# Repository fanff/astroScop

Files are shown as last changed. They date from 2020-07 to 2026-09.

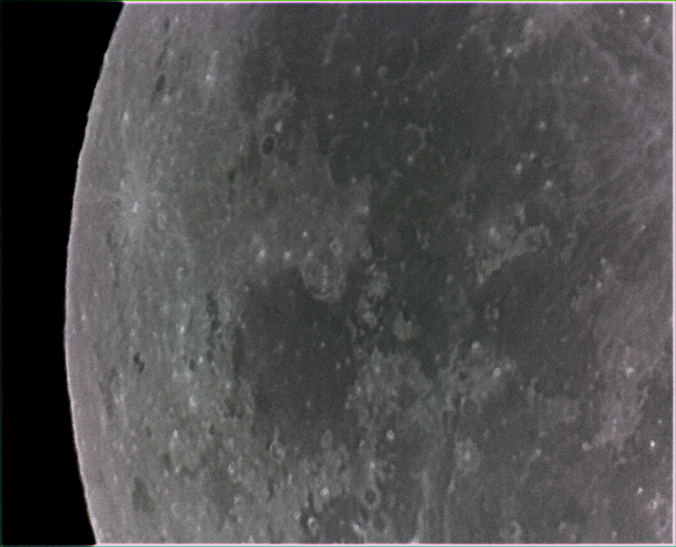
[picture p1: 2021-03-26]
backapp/testimgs/moon2.jpg

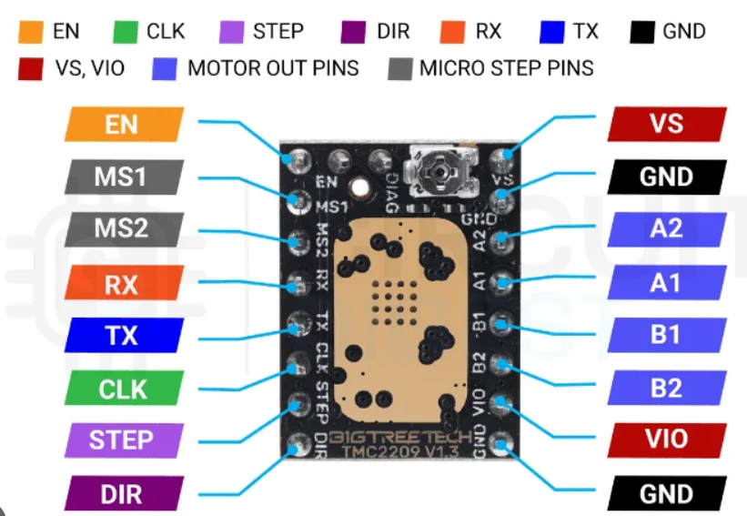
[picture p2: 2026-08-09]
firm/TMC2209.png

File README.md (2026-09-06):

# astroScop

Raspberry Pi HQ camera + dual-axis stepper telescope control, with a Vue UI and optional Bayer post-processing for Siril.

```text
UI (wasp) ──WebSocket──► rootserver :8765
                              │
              ┌───────────────┼───────────────┐
              ▼               ▼               ▼
        cam_picamera2    motorControl     guideControl
        (picamera2)      (USB serial)     (isolate+PI)
              │               │               │
              ▼               ▼               │
           IMX477          Pico 2 W ◄─────────┘
                           (ASC + DEC, mixer)
```

## Layout

| Path | Role |
|---|---|
| [`backapp/`](backapp/) | Pi services: WebSocket hub, HQ camera worker, motor worker |
| [`firm/pico2w/`](firm/pico2w/) | MicroPython firmware for Pico 2 W (ASC/DEC STEP/DIR) |
| [`webapp/wasp/`](webapp/wasp/) | Vue 3 + Vite control UI |
| [`postprocessing/`](postprocessing/) | Bayer `.npy` → CFA FITS for Siril (`astroscop-pp`) |

## Pi services

Installed via [`backapp/deploy/install_on_pi.sh`](backapp/deploy/install_on_pi.sh)
(after syncing code with [`backapp/deploy/deploy.ps1`](backapp/deploy/deploy.ps1) / [`backapp/deploy/deploy.sh`](backapp/deploy/deploy.sh)):

| systemd unit | Process |
|---|---|
| `astroscop-rootserver` | [`backapp/rootserver.py`](backapp/rootserver.py) — WS hub |
| `astroscop-camera` | [`backapp/cam_picamera2.py`](backapp/cam_picamera2.py) — HQ capture + preview |
| `astroscop-motor` | [`backapp/motorControl.py`](backapp/motorControl.py) — rates ↔ Pico |
| `astroscop-guide` | [`backapp/guideControl.py`](backapp/guideControl.py) — isolate + PI; trims to mixer (`GUIDE_ENABLE` still required) |

Camera settings contract (wire format, slow/fast fields): [`backapp/docs/camera-settings-contract.md`](backapp/docs/camera-settings-contract.md).  
Hardware / modes / science notes: [`backapp/docs/pi-hq-camera.md`](backapp/docs/pi-hq-camera.md).

## Firmware (Pico 2 W)

See [`firm/README.md`](firm/README.md) and [`firm/pico2w/README.md`](firm/pico2w/README.md).

```bash
cd firm/pico2w
mpremote connect COM5 cp main.py :main.py
mpremote connect COM5 reset
```

Host client: [`backapp/pico_motor.py`](backapp/pico_motor.py).

## UI (wasp)

```bash
cd webapp/wasp
npm install
npm run serve    # dev
npm run build    # production
```

Pi deploy (compiled static files on **port 80**, hub still `ws://<host>:8765`).
SSH host defaults to `piscope`; set `ASTROSCOP_PI_HOST` for another Pi (e.g. `piscope2`).

```bash
# Windows — backend then UI
$env:ASTROSCOP_PI_HOST = "piscope2"
powershell -File backapp/deploy/deploy.ps1
cd webapp/wasp; npm run deploy:pi

# bash
ASTROSCOP_PI_HOST=piscope2 ./backapp/deploy/deploy.sh
ASTROSCOP_PI_HOST=piscope2 ./webapp/wasp/deploy/deploy.sh
```

See [`webapp/wasp/README.md`](webapp/wasp/README.md).

## Post-processing

Convert science Bayer captures to Siril-friendly FITS:

```bash
cd postprocessing
# see postprocessing/README.md
```

## Evolution (planning)

| Document | Status |
|---|---|
| [`docs/evolution-vision-motor-control-loop.md`](docs/evolution-vision-motor-control-loop.md) | Plan: camera-star PID trims on top of sidereal ASC + DEC (polar alignment is close, not perfect) |

## Dev notes

- [`backapp/`](backapp/) is **uv-managed** (`pyproject.toml` + `uv.lock`). Dev: `cd backapp && uv sync`.
- Pi install does **not** need uv: on a host run [`backapp/deploy/export_pi_requirements.sh`](backapp/deploy/export_pi_requirements.sh), sync `deploy/requirements.generated.txt` to the Pi, then run [`backapp/deploy/install_on_pi.sh`](backapp/deploy/install_on_pi.sh). That script creates a `.venv` with `--system-site-packages`, `pip install`s the export, and keeps **apt** packages for picamera2 / numpy / opencv / PIL.
- Preview helpers live in [`backapp/imgutils.py`](backapp/imgutils.py); Bayer science saves go through [`backapp/cam_storage.py`](backapp/cam_storage.py).

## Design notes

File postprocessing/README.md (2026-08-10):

# Offline Bayer → Siril CFA FITS

Convert astroScop science captures (`frame_*_bayer.npy` + `frame_*_meta.json`) into a numbered series of **undebayered CFA** FITS files that Siril can stack.

This package is for an **x86 processing PC**. It is not deployed on the Pi or telescope.

## Requirements

- Python ≥ 3.12
- [uv](https://github.com/astral-sh/uv) (recommended)

## Install / run

```powershell
cd postprocessing
uv sync --group dev
uv run astroscop-pp convert D:\cko\astropic\sat1 -o D:\cko\astropic\sat1_siril --basename lights
```

Useful flags:

| Flag | Meaning |
|---|---|
| `--limit N` | Convert only the first N frames (smoke test) |
| `--dry-run` | List planned outputs without writing |
| `--overwrite` | Replace existing `.fits` |
| `--no-recursive` | Do not scan one subdirectory level (`bigs/`, etc.) |

## What the converter does

1. Pairs `*_bayer.npy` with `*_meta.json`, sorted by `sequence`
2. Crops stride padding using `raw.configured_size` `[W, H]` (e.g. 2032 → 2028)
3. Maps `SBGGR12` → FITS `BAYERPAT=BGGR` (no demosaic)
4. Writes `lights_00001.fits`, `lights_00002.fits`, … plus `conversion_manifest.json`

## Siril

1. Set the working directory to the output folder.
2. In **Conversion**, add the `.fits` files and use sequence name `lights` (or load the sequence if already named).
3. Keep **Debayer unchecked** through calibration / registration of OSC lights; debayer after preprocessing if you follow a colour workflow.
4. For current HQ captures, Bayer pattern should read as **BGGR**.

## Tests

```powershell
cd postprocessing
uv run pytest
```

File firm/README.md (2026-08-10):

# Telescope firmware (Pico 2 W)

MicroPython firmware for the **Raspberry Pi Pico 2 W**.

Host protocol (USB serial commands for the Raspberry Pi) lives next to the boot script:

→ **[`pico2w/README.md`](pico2w/README.md)**

Pi host for ASC+DEC is `backapp/motorControl.py` + `backapp/pico_motor.py` (systemd: `astroscop-motor`).

## Current status

- **ASC** and **DEC** motors are wired and controlled in **STEP/DIR** standalone mode (no TMC UART config yet).
- Pico emits regular STEP pulses from sparse USB commands (`asc` / `dec` with `dir`, `step_us`).
- Rate setpoints ease over ~100 ms (signed rate); step deadline is not reset on change.
- **CLK** on the TMC is left **open** (internal oscillator). Do not drive it from the Pico.
- TMC PDN UART is still unresolved; probes are kept under `pico2w/tests/`.

Current is set with the TMC **VREF** pot until UART works. Keep common **GND** between Pico, TMC, and 12V PSU (−).

## Hardware

The Pico 2 W will drive **two TMC2209** boards (ASC + DEC).

| Signal | Role (today) |
|---|---|
| **EN** | Enable / disable driver (active-low `ENN`) |
| **STEP** / **DIR** | Motion |
| **CLK** | Leave open on TMC |
| **PDN / UART** | Planned; not used by `main.py` yet |

### Pin map (Pico 2 W ↔ TMC2209)

Physical pin numbers are the board edge connector pins.

**Motor 1 — ASC**

| TMC2209 | Pico 2 W GPIO | Board pin | Color |
|---|---|---|---|
| DIR | GP10 | 14 | Green |
| STEP | GP11 | 15 | White |
| EN | GP12 | 16 | Grey |
| CLK | (open on TMC) | — | — |
| PDN (future UART) | GP16 / GP17 + 1k single-wire | 21 / 22 | Blue / Yellow |

**Motor 2 — DEC**

| TMC2209 | Pico 2 W GPIO | Board pin | Color |
|---|---|---|---|
| DIR | GP18 | 24 | Green |
| STEP | GP19 | 25 | White |
| EN | GP20 | 26 | Grey |
| CLK | (open on TMC) | — | — |
| PDN (future UART) | GP8 / GP9 + 1k single-wire | 11 / 12 | Blue / Yellow |

## First-run setup

### 1. Flash MicroPython

1. Download the official MicroPython UF2 for **Pico 2 W**:
   https://micropython.org/download/RPI_PICO2_W/
2. Hold **BOOTSEL**, plug in USB, release BOOTSEL.
3. Copy the `.uf2` onto the `RPI-RP2` drive.

### 2. Install the upload tool

```bash
uv tool install mpremote
```

## Upload firmware

```bash
cd firm/pico2w
mpremote connect COM5 cp main.py :main.py
mpremote connect COM5 reset
```

On this machine the Pico is usually **COM5** (`2e8a:0005`).

Smoke-test over the USB REPL:

```bash
mpremote connect COM5 repl
```

Then type:

```text
ping
asc dir=1 step_us=2000
dec dir=0 step_us=2000
status
stop
```

### Hardware tests (optional)

```bash
mpremote connect COM5 run tests/test_step_burst.py
mpremote connect COM5 run tests/test_dec_step_burst.py
mpremote connect COM5 run tests/test_tmc_uart_pdn.py
```

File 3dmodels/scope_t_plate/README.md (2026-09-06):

# Scope T-plate

OpenSCAD **T-shaped** mounting plate for a scope on a bar. Same geometry
family as `marks_holder`, with each feature named and switchable.

## Features

Each block is a Customizer group. Booleans under **Features** turn cuts on or
off without changing the T outline.

- **T body** — horizontal crossbar plus vertical stem. `stem_length` is how
  far the stem extends past the bar; `stem_from_center` slides the stem along Y
- **Rails** — two rectangular channels on the underside of the crossbar
  (`rail_length`, `rail_width`, `rail_depth`, `rail_inner_gap`)
- **Crossbar M4 taps** — two Ø3.3 mm tap-drill holes on the bar, spaced by
  `m4_tap_spacing` and centred on the bar midpoint
- **Deck** — thinner filling plate in the open T corner, united with the T
  before corner rounding, with a 10×10 mm grid of Ø2.5 mm M3 tap holes
  (`deck_hole_spacing`, `m3_tap_diameter`)
- **Scope mount** (optional) — two 1/4"-20 clearance holes on the crossbar,
  mirrored about the plate centre along Y; `scope_screw_from_center` is the
  offset of each hole from that centre
- **Pi camera mount** (optional) — M3 through-hole on the stem plus an M3-wide
  arc slot centred on that hole so the camera can pivot; `pi_arc_angle` is the
  total sweep, `m3_clearance_diameter` is the pass-through size

## Mode

Customizer **Mode** → `testing` or `normal`.

Switched sizes (testing → normal): plate height, deck height, and
deck max X. Other dimensions stay shared.

## Usage

Open `scope_t_plate.scad` in [OpenSCAD](https://openscad.org/), adjust
parameters if needed, then **Export → STL**.

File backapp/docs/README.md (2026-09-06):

# astroScop camera docs

Docs for the Raspberry Pi HQ (IMX477) camera path used by agents and operators.

| Document | Purpose |
|---|---|
| **[`camera-settings-contract.md`](camera-settings-contract.md)** | **Start here for rootserver + UI work** — wire format, slow/fast fields, forbidden keys, WS messages |
| [`pi-hq-camera.md`](pi-hq-camera.md) | Hardware, sensor modes, science notes, safe live testing on `piscope` |
| [`hq-camera-capability-report.md`](hq-camera-capability-report.md) | Verified capability suite results (modes, exposure trust, ScalerCrop behaviour) |
| [`cam-settings-bench-report.md`](cam-settings-bench-report.md) | Latest typed-settings / spectrum / reconfig bench (must stay PASS) |
| [`guide-bench-report.md`](guide-bench-report.md) | Latest autoguide Pi timing benches (Phase B geom first; isolate/crop/worker later) |
| [`../../docs/evolution-vision-motor-control-loop.md`](../../docs/evolution-vision-motor-control-loop.md) | Autoguide loop evolution (phased A–H; Phase B geom is in code) |

## Code back-links

| Path | Role |
|---|---|
| [`../cam_settings.py`](../cam_settings.py) | Enforced `CameraSettings` model |
| [`../cam_spectrum.py`](../cam_spectrum.py) | Display RGB spectrum |
| [`../ws_messages.py`](../ws_messages.py) | Hub WS envelopes + params normalize |
| [`../cam_picamera2.py`](../cam_picamera2.py) | Camera worker |
| [`../cam_storage.py`](../cam_storage.py) | Bayer storage process (shm ring) |
| [`../test_cam_storage.py`](../test_cam_storage.py) | Storage process unit tests |
| [`../rootserver.py`](../rootserver.py) | WebSocket hub (typed params, passthrough preview) |
| [`../test_cam_settings_bench.py`](../test_cam_settings_bench.py) | Contract bench (on-Pi) |
| [`../test_rootserver_hub.py`](../test_rootserver_hub.py) | Camera-free hub live tests |
| [`../scripts/run_cam_settings_bench.ps1`](../scripts/run_cam_settings_bench.ps1) | Sync + run camera settings bench on Pi |
| [`../guide_geom.py`](../guide_geom.py) | Pixel error → arcsec / motor step-error (`cos δ`, pole gate) |
| [`../guide_roi.py`](../guide_roi.py) | Tracking lock → native RGB ROI rectangle |
| [`../guide_isolate.py`](../guide_isolate.py) | Star isolation on a small RGB tile |
| [`../guide_handoff.py`](../guide_handoff.py) | Native RGB crop + shm tile slot for the guide worker |
| [`../guide_pid.py`](../guide_pid.py) / [`../guideControl.py`](../guideControl.py) | PI worker (trims off until F/H) |
| [`../test_guide_geom.py`](../test_guide_geom.py) | Geometry unit tests (laptop) |
| [`../test_guide_roi.py`](../test_guide_roi.py) / [`../test_guide_isolate.py`](../test_guide_isolate.py) | ROI + isolation unit tests (laptop) |
| [`../scripts/run_guide_bench.ps1`](../scripts/run_guide_bench.ps1) | Sync + run guide benches on Pi (`-Stage geom\|isolate`) |
| [`../deploy/astroscop-camera.service`](../deploy/astroscop-camera.service) | Production worker unit |

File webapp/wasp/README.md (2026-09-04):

# wasp

Vue 3 + Vite UI for the astroScop telescope hub (`ws://host:8765`).

Emits canonical `CameraSettings` (`params`) and motor `ctlparams` per
`backapp/docs/camera-settings-contract.md`.

## Setup

```
npm install
```

### Dev server

```
npm run serve
```

Connects to `ws://<page-hostname>:8765` by default (override in the toolbar).

### Production build

```
npm run build
```

## Deploy to the Pi (`piscope`, port 80)

The UI is compiled on the host, copied to the Pi, and served by nginx on
port 80. The browser talks to the hub on the **same hostname** as the page
(`ws://piscope:8765` when you open `http://piscope/`).

From Windows (PowerShell), in `webapp/wasp`:

```
npm run package:pi    # npm ci + production build → dist/
npm run deploy:pi     # package, then install on piscope
```

From bash:

```
./deploy/package.sh
./deploy/deploy.sh
```

Override the SSH host with `ASTROSCOP_PI_HOST` (default `piscope`).

On the Pi, `deploy/install_on_pi.sh` installs nginx, publishes
`/var/www/astroscop`, and enables the site. Re-run `deploy.ps1` / `deploy.sh`
after UI changes.

`./buildandpush.sh` remains a wrapper around `deploy/deploy.sh`.

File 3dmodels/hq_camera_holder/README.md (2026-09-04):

# HQ camera holder

OpenSCAD enclosure that screws a Raspberry Pi High Quality Camera (CS-mount)
onto a telescope nosepiece, or leaves the CS mount free for a CS lens.

The **cover is frozen**. Already-printed caps still fit every body. Do not
change plate outline, cover walls, or screw spacing in
`hq_camera_holder_lib.scad`.

## Files

| File | Print / tweak |
|---|---|
| `cover.scad` | Back cap (unchanged geometry) |
| `body_1_25.scad` | 1.25" nosepiece |
| `body_2.scad` | Short, open 2" nosepiece (near focus) |
| `body_open.scad` | Plate only — CS threads free for a CS lens |
| `hq_camera_holder_lib.scad` | Shared modules; not a part |

Open the file for the part you want in [OpenSCAD](https://openscad.org/),
render (F6), then **Export → STL**.

Body files also have an **assembly** Customizer option: preview of that body
plus the cover. `show_camera_preview` is a ghost overlay in **Preview** (F5)
only; it is not in a full render or STL.

## Features

- **1.25" nosepiece** — barrel for a standard focuser, chamfer, optional
  safety groove, hulled into the camera plate
- **2" nosepiece** — ~12 mm stub, 50.8 mm OD minus print clearance, inner
  bore wider than the CS clearance (no 1.25"-style tunnel)
- **Open CS** — no barrel; CS-mount sticks through the plate; corner bosses
  take the cover screws
- **CS-mount hollow** — clearance for the aluminium CS-mount, tripod-lug
  slot on the −Y side
- **Camera plate** — PCB face at z = 0, four M2.5 tap holes on the 30 mm
  square
- **Back cap** — shallow box with a fat rim on the plate at z = 0; M2.5
  through-holes line up with body taps; ribbon slot on +Y

Camera geometry follows the official HQ CS-mount drawing: 38 mm PCB, Ø2.5
holes on a 30 mm square, CS-mount about Ø36 mm. Barrel ODs use the same
print-clearance convention as the other telescope adaptors in this folder.

## Usage

The body lies on its flat camera face with the nosepiece (if any) pointing
+Z. Print the cover outer-face down, cavity up.

Seat the HQ camera CS-mount through the plate (tripod lug toward −Y), fasten
with four M2.5 screws, route the ribbon out the +Y slot, then close the cap
with M2.5 screws into the plate. Body holes are Ø2.1 mm, ready to tap M2.5.

If a nosepiece is tight or loose in the focuser, change `outer_clearance` in
that body file. If the CS-mount is snug, change `cs_mount_clearance` in the
lib (that affects every body, not the cover).

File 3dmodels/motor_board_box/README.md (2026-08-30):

# Motor board box

Parametric OpenSCAD enclosure for the Raspberry Pi motor-control board and its
power and motor wiring.

## Features

- **Bottom box** — rounded enclosure with configurable walls, floor, and internal clearances
- **Board grooves** — full-length triangular ribs under both long edges, tapering toward the floor, plus short snap-fit tabs above the board
- **Cable exits** — separate features for the two flat motor wires and the USB wire
- **Power adaptor pocket** — floor block hollowed by the isolated adaptor in `barrel_adapter.scad`, opening through the end wall
- **Strap loops** — three C-shaped loops on each long wall, with ramps from the wall so they print without hanging
- **End-wall vents** — vertical slots through the short wall opposite the power adaptor
- **Screw posts** — corner posts intended to be tapped for the cover screws
- **Cover** — separate printable plate with clearance holes, a locating lip with gaps at the motor and USB wire exits, and radial airflow slots

Box dimensions live in `motor_board_box.scad`. Adaptor shape dimensions live
only in `barrel_adapter.scad`.

## Part selection

Use the OpenSCAD Customizer **Output** section:

- `bottom` — render the enclosure body for export
- `cover` — render the cover in its print orientation
- `assembly` — preview the closed enclosure

Open `barrel_adapter.scad` on its own to iterate the 12V adaptor. The box
imports only its modules (`use`) and hollows that shape through the end wall.

`show_board_preview` and `show_adapter_preview` are ghost overlays in
**Preview** (F5) on `bottom` and `assembly`. They do not appear in a full
**Render** (F6) and are not part of an exported STL.

Individual feature switches can hide the grooves, cable exits, adaptor pocket,
strap loops, screw mounts, cover lip, cover vents, or end-wall vents during
development.

## Usage

Open `motor_board_box.scad` in [OpenSCAD](https://openscad.org/), select the
required part, render it, then use **Export → STL**. Export `bottom` and `cover`
separately.

Adaptor shape parameters live only in `barrel_adapter.scad`. Placement of that
pocket on the box lives in `motor_board_box.scad`.

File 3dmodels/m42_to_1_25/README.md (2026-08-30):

# M42 → 1.25" eyepiece

OpenSCAD adaptor ring: female M42 thread on one end, 1.25" eyepiece socket on the other.

## Features

- **Body** — outer cylinder sized for a comfortable wall around the M42 thread
- **M42 end** — female M42×0.75 (T2) thread to screw onto a male M42 nose
- **Eyepiece end** — bore for a standard 1.25" eyepiece barrel, with a stop lip so the eyepiece cannot fall through
- **Set screw** — optional radial hole to lock the eyepiece

## Mode

Customizer **Mode** → `testing` or `normal` switches overall height, thread length, eyepiece depth, and mesh density.

Thread clearance, eyepiece clearance, and set-screw size are adjustable for print fit.

## Usage

Open `m42_to_1_25.scad` in [OpenSCAD](https://openscad.org/), set **Mode** to `normal` for a final part, adjust clearances if needed, then **Export → STL**.

Print with the axis vertical; check the M42 fit on a known male T2 / M42 nose before relying on it at the telescope.

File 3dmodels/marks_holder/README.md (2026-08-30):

# Marks holder

OpenSCAD **T-shaped** plate that mounts a Pi camera tracking head and a small Maksutov refractor.

## Features

- **Stem (vertical arm)** — Pi camera mount; length and Y offset toward the Maksutov are tunable
- **Crossbar (horizontal arm)** — Maksutov mount; length is tunable
- **Rounded corners** — outer tips of the T and inner fillets at the stem/crossbar junction
- **Strap deck** — lower plain plate in the open corner of the T; united with the stem and crossbar before corner rounding, with a grid of rectangular slots for straps / rubber bands
- **Pi camera mount** — two M4 clearance holes matching the existing tracking mount spacing
- **Maksutov mount** — standard camera tripod screw hole, recessed rectangular pocket in the top face; screw position is offset from the crossbar centre along Y by a tunable parameter
- **Crossbar taps** — two M4 tap-drill holes on the horizontal arm, spaced apart and centred on the bar midpoint
- **Bottom hollows** — two rectangular cavities cut from the underside of the crossbar, centred on Y, with a tunable gap between their inner walls

## Mode

Customizer **Mode** → `testing` or `normal`.

Switched sizes (testing → normal): plate height, hollow depth, strap-deck height, and strap-deck max X. Other dimensions stay shared.

## Usage

Open `marks_holder.scad` in [OpenSCAD](https://openscad.org/), adjust parameters if needed, then **Export → STL**.

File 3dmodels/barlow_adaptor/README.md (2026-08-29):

# Barlow adaptor

OpenSCAD ring that spaces a Barlow to a fixed length for a 2" focuser.

## Dimensions

- **Outer diameter** — fits a standard 2" telescope mount / focuser barrel
- **Inner diameter** — bore for the Barlow body
- **Height** — adaptor length along the optical axis

Clearance parameters (`outer_clearance`, `inner_clearance`) can be tuned for print fit.

## Usage

Open `barlow_adaptor.scad` in [OpenSCAD](https://openscad.org/), adjust parameters if needed, then **Export → STL**.

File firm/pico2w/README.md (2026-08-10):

# Pico 2 W ↔ Raspberry Pi — ASC + DEC stepper protocol

Sparse **USB serial** (CDC) text commands. The Pico generates STEP pulses on its own; the Pi only sends occasional setpoints (direction + step period). No continuous streaming required.

## Role split

| Side | Responsibility |
|---|---|
| **Raspberry Pi** | Compute tracking rate → `dir` + `step_us`; send when it changes |
| **Pico 2 W** | Enable drivers, set DIR, emit STEP edges; ease rate changes over ~100 ms |
| **TMC2209** | Standalone STEP/DIR for now (VREF pot = current). TMC UART config later if/when PDN works |

Motors: **ASC** (Motor 1) and **DEC** (Motor 2).

## Link

- Transport: Pico USB serial (same port as `mpremote`, e.g. `COM5` on Windows)
- Encoding: UTF-8 / ASCII lines
- Line ending: `\n` ( `\r\n` accepted)
- Baud: N/A for USB CDC (host opens the virtual COM port; 115200 is fine if a baud must be set)

## Command format

```
<cmd> [key=value] [key=value] ...
```

Whitespace-separated. Keys are case-insensitive. Unknown commands get an error line.

### Commands (implemented on Pico)

| Command | Meaning |
|---|---|
| `ping` | Liveness check |
| `status` | Report ASC + DEC commanded state |
| `stop` | Immediate disable both drivers |
| `asc ...` | Set ASC motion parameters |
| `dec ...` | Set DEC motion parameters |

Alias: `motor` is accepted as the same as `asc`.

### `asc` / `dec` parameters

| Key | Values | Meaning |
|-----|---|---|
| `dir` | `0` or `1` | Direction pin level (commanded) |
| `step_us` | integer µs | Target period between STEP rising edges. `0` = ramp to stop |
| `step_time` | integer µs | **Alias of `step_us`** (same units) |
| `en` / `enable` | `0` or `1` | `0` = immediate hard stop for that axis. If omitted and `step_us>0`, Pico enables automatically |

Limits on Pico: `step_us` clamped to **50 … 10_000_000** µs.

### Examples (Pi → Pico)

```text
ping
asc dir=1 step_us=2000
dec dir=0 step_us=3000
asc dir=0 step_time=1500
asc step_us=0
stop
status
```

### Replies (Pico → Pi)

One line per handled command. No periodic telemetry unless the Pi asks (`status` / after `asc`/`dec`).

| Reply | Meaning |
|---|---|
| `ok boot motor=asc,dec` | Firmware started |
| `ok pong` | `ping` |
| `ok motor=asc\|dec en=<0\|1> dir=<0\|1> step_us=<n>` | After `asc` / `dec` (commanded target) |
| `ok asc en=… dir=… step_us=… dec en=… dir=… step_us=…` | After `status` |
| `ok stopped` | After `stop` |
| `err ...` | Parse / unknown command |

## Timing semantics

- `step_us` = full period between steps (not the pulse width).
- Pico STEP high time is a short fixed pulse (~4 µs); low fills the rest of the period.
- Rate ≈ `1e6 / step_us` steps per second.
- **Rate changes** (including reverse / start / `step_us=0`) ease as a **signed** steps/s ramp over **~100 ms**. The step deadline is **not** reset on setpoint change (avoids ghost steps / “bzz”).
- `stop` and `en=0` are **immediate** hard cuts (no ramp).
- No microstepping control from software yet: driver MS pins / pot define the mechanical step size.
- If the Pico falls behind, it resyncs (does not dump a burst of catch-up steps).

## Host on the Raspberry Pi (live)

Production host:

| Piece | Path |
|---|---|
| Serial client | `backapp/pico_motor.py` |
| Worker (WS ↔ serial) | `backapp/motorControl.py` |
| systemd | `backapp/deploy/astroscop-motor.service` |
| Smoke test | `backapp/test_pico_motor_firmware_win.py --port /dev/ttyACM0` |

UI sends `ctlparams` `{k:"ASC"|"DEC", v:<signed steps/sec>}`. The worker maps that to
`asc|dec dir=… step_us=…` (`step_us = 1e6 / |v|`, stop on `0`).

```bash
# Manual protocol check (stop motor worker / mpremote first)
cd /home/fanf/astroScop/backapp
python3 -c "from pico_motor import PicoMotorClient, resolve_pico_port; c=PicoMotorClient(resolve_pico_port()); print(c.drain_boot()); print(c.ping()); c.close()"
```

Open the port **without** leaving a second tool (`mpremote repl`) attached.

## Pin map

### ASC = Motor 1

| Signal | Pico GPIO | Notes |
|---|---|---|
| DIR | GP10 | |
| STEP | GP11 | |
| EN | GP12 | Active-low on TMC (`ENN`) |
| TMC UART | GP16/GP17 | Not used by `main.py` yet |

### DEC = Motor 2

| Signal | Pico GPIO | Notes |
|---|---|---|
| DIR | GP18 | |
| STEP | GP19 | |
| EN | GP20 | Active-low on TMC (`ENN`) |
| TMC UART | GP8/GP9 | Not used by `main.py` yet |

CLK: leave **open** on both TMCs (internal oscillator). Common **GND** between Pico, TMC, and 12V PSU (−). VM=12V on TMC. VREF pot sets current.

## Upload

```bash
cd firm/pico2w
mpremote connect COM5 cp main.py :main.py
mpremote connect COM5 reset
```

Manual check:

```bash
mpremote connect COM5 repl
# then type: ping
#          asc dir=1 step_us=2000
#          dec dir=0 step_us=2000
#          status
#          stop
```

## Tests (not installed as boot)

| Script | Purpose |
|---|---|
| `tests/test_step_burst.py` | ASC STEP/DIR smoke test (no serial protocol) |
| `tests/test_dec_step_burst.py` | DEC STEP/DIR smoke test (GP18/19/20, no UART) |
| `tests/test_tmc_uart_pdn.py` | TMC PDN UART probe (still unresolved) |

```bash
mpremote connect COM5 run tests/test_step_burst.py
mpremote connect COM5 run tests/test_dec_step_burst.py
```

## Future (not in this firmware)

- TMC UART current / microstep config once PDN wiring works
- Optional Bluetooth link instead of USB

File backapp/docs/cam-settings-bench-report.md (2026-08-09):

# Camera settings / spectrum / reconfig — bench report

Generated: **2026-08-09 12:50:35 UTC**  
Run: `settings_20260809T145000`  
Duration: **27.05 s**  
Overall: **PASS**

**Contract under test:** [`camera-settings-contract.md`](camera-settings-contract.md) (`CameraSettings` in [`cam_settings.py`](../cam_settings.py))  
**Docs index:** [`README.md`](README.md)

- Manifest: [`manifest.json`](../cam_test_out/settings_20260809T145000/manifest.json)
- Run folder: [`C:/Users/franc/cko/astroScop/backapp/cam_test_out/settings_20260809T145000`](../cam_test_out/settings_20260809T145000)

## Verdict

All assertions passed. Acquisition, fast/slow apply, spectrum, and 8 fps emit policy behaved predictably on full-frame worst case.

## Cases

### Settings model

```json
{
  "ok": true,
  "diff_slow": {
    "slow_changed": true,
    "fast_changed": true,
    "output_changed": false,
    "changed_fields": [
      "sensor_preset",
      "shutter_us",
      "analog_gain",
      "colour_gain_r",
      "colour_gain_b"
    ]
  },
  "diff_fast": {
    "slow_changed": false,
    "fast_changed": true,
    "output_changed": false,
    "changed_fields": [
      "analog_gain"
    ]
  }
}
```

### Open full (4056×3040)

- open_s: **0.8393**
- mode_size: `[4056, 3040]`

full preview

### Capture timings (full RGB)

| i | shape | capture_s | shutter_us | gain |
|---|---|---|---|---|
| 0 | [3040, 4056, 3] | 0.5684 | 19979 | 1.0 |
| 1 | [3040, 4056, 3] | 0.2794 | 19979 | 1.0 |
| 2 | [3040, 4056, 3] | 0.2794 | 19979 | 1.0 |

### Spectrum (256-bin RGB)

- full-res compute: **3.8837 s**
- display 640×480 compute: **0.0924 s**
- bins: 256 (hist_len=256)
- display mean R: 0.00015950520833333333

- [`spectrum_display.json`](../cam_test_out/settings_20260809T145000/spectrum_display.json)

### Fast apply (set_controls)

| apply_s | req gain | got | req shutter | got |
|---|---|-----|---|-----|
| 0.0012 | 1.0 | 1.0 | 100000 | 99954 |
| 0.0012 | 1.15 | 1.1492705345153809 | 110000 | 109985 |
| 0.0012 | 1.3 | 1.299492359161377 | 120000 | 119989 |
| 0.0012 | 1.45 | 1.4483734369277954 | 130000 | 129992 |
| 0.0012 | 1.6 | 1.600000023841858 | 140000 | 139996 |

### Slow apply (reconfigure)

| apply_s | preset | mode_size |
|---|---|---|
| 0.3154 | bin2x2 | [2028, 1520] |
| 0.3341 | full | [4056, 3040] |

### Emit path ≤8 fps (resize + spectrum + JPEG)

- emitted/skipped: **30** / **0**
- emit_fps: **2.3757**
- mean/max process_s: 0.1357 / 0.1718

## Contract reminders

- Canonical gain: `analog_gain` only (ISO stripped if present).
- Slow: `sensor_preset` / main size / `include_raw`.
- Fast: shutter, analogue gain, colour gains, ScalerCrop.
- Live spectrum runs on display RGB (256 bins/channel).
- Hard limit: on full 4056×3040, FrameDurationLimits min is ~85 ms — shorter shutter requests clamp.

```powershell
powershell -File backapp/scripts/run_cam_settings_bench.ps1
```

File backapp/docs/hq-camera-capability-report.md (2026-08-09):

# Pi HQ Camera (IMX477) — capability report

Generated: **2026-08-09 12:02:30 UTC**  
Suite run: `20260809T140213`  
Host: `piscope` / Raspberry Pi HQ camera  
Suite duration: **5.33 s**  
Bayer raw enabled end-to-end: **True**

**Settings / wire contract for rootserver + UI:** [`camera-settings-contract.md`](camera-settings-contract.md)  
**Hardware & ops overview:** [`pi-hq-camera.md`](pi-hq-camera.md) · [docs index](README.md)

This report aggregates the live suite outputs so you can eyeball what the hardware
can and cannot do (modes, bit depth, exposure trust, and timing/framerate limits).

- Manifest: [`manifest.json`](../cam_test_out/20260809T140213/manifest.json)
- Probe: [`probe.json`](../cam_test_out/20260809T140213/probe.json)
- Run folder: [`C:/Users/franc/cko/astroScop/backapp/cam_test_out/20260809T140213`](../cam_test_out/20260809T140213)

## Executive summary

| Test | Verdict | Mode | Depth | Exposure req→got | Proc (s) | Filesize |
|---|---|---|---|---|---|---|
| [`full`](#full) | PASS | bayer | 12-bit | 50000→49963 | 1.0393 | 23.6 MiB |
| [`bin2x2`](#bin2x2) | PASS | bayer | 12-bit | 50000→49992 | 0.1926 | 5.9 MiB |
| [`bin2x2_crop`](#bin2x2-crop) | PASS | bayer | 12-bit | 50000→49999 | 0.0785 | 2.5 MiB |
| [`crop`](#crop) | PASS | bayer | 12-bit | 50000→49963 | 0.2803 | 23.6 MiB |
| [`fast`](#fast) | PASS | bayer | 12-bit | 5000→4996 | 0.1998 | 5.9 MiB |

## Hard limits & trustable operating range

Findings from this hardware + software stack:

1. **Bayer RAW is available** (`SBGGR12` unpacked uint16). Prefer this for signal work; do not demosaic on the Pi during acquisition.
2. **AE/AWB can be forced off**; colour gains stay fixed — good for constant-parameter series.
3. **Long exposures**: requested `ExposureTime` tracks metadata closely through at least the longest test in this run (see long_* sections). `FrameDurationLimits` on this Pi allow multi-minute caps.
4. **ScalerCrop** changes the **RGB main FOV** but does **not** shrink the Bayer raw buffer (still full sensor). For less data / faster raw, use a binned sensor mode (`bin2x2`), not crop alone.
5. **Framerate hard floor** is exposure time (and sensor `FrameDuration`). Suite disk writes (npy+bmp) are much slower than RAM stacking — production should keep frames in RAM.
6. **Bayer width may be stride-padded** (e.g. 4064 vs 4056) — crop using `configured_size` from metadata.
7. Daytime long frames will **saturate** (mean near 4095 on 12-bit). That does not invalidate exposure-control tests.
8. **Suite timing caveat (this run):** early suite builds captured Bayer then RGB as two requests, so long-* `processing_s` ≈ **2× exposure** (e.g. 120 s → ~360 s wall). Exposure metadata itself is still trustworthy. Newer suite code uses a single `capture_request()` for raw+main.

### Sensor modes seen in probe

Count: **15**

Sizes: `1332×990`, `2028×1080`, `2028×1520`, `4056×2160`, `4056×3040`

---

# Per-test details

## `full`

**PASS** — as expected

preview full

| Field | Value |
|---|---|
| Acquisition mode | `bayer` + RGB preview |
| Sensor mode size | `[4056, 3040]` |
| Bayer / science shape | `[3040, 4064]` |
| RGB shape | `[3040, 4056, 3]` |
| Color depth | **12-bit** (`SBGGR12`) |
| Science dtype | `uint16` |
| Science filesize | 23.6 MiB |
| Preview filesize | 898.2 KiB |
| Requested exposure | 0.05 s / µs |
| Got exposure | 0.049963 |
| Exposure check | err=37 µs (0.074%) |
| AnalogueGain | `1.0` (req `1.0`) |
| ColourGains | R=`1.0` B=`1.0` |
| ScalerCrop | `[0, 0, 4056, 3040]` |
| FrameDuration | `85335` µs |
| Science mean | `3617.8707142949647` |
| RGB mean | `187.98824129403266` |

### Timing

| Metric | Seconds |
|---|---|
| Requested exposure | 0.05 |
| Got exposure | 0.049963 |
| FrameDuration | 0.085335 |
| Acquire (single request) | 0.6716 |
| Acquire raw (legacy split) | n/a |
| Acquire RGB (legacy split) | n/a |
| Save science `.npy` | 0.0259 |
| Save preview BMP | 0.2303 |
| Processing total (suite path) | 1.0393 |
| Single-request capture | True |

### Framerate estimates

| Estimate | FPS | Period (s) | Meaning |
|---|-----|---|---|
| Exposure-limited max | 11.719 | 0.085335 | Cannot exceed 1/exposure (or FrameDuration) |
| Suite+disk observed | 0.962 | 1.0393 | This harness (raw+rgb+npy+bmp) |
| RAM science estimate | 1.489 | 0.6716 | Keep arrays in RAM, skip disk (production-like) |

### Files

- Science: [`frame_000_bayer.npy`](../cam_test_out/20260809T140213/full/frame_000_bayer.npy)
- Preview: [`frame_000_preview.bmp`](../cam_test_out/20260809T140213/full/frame_000_preview.bmp)
- Meta: [`frame_000_meta.json`](../cam_test_out/20260809T140213/full/frame_000_meta.json)
- Preset: [`preset.json`](../cam_test_out/20260809T140213/full/preset.json)

---

## `bin2x2`

**PASS** — as expected

preview bin2x2

| Field | Value |
|---|---|
| Acquisition mode | `bayer` + RGB preview |
| Sensor mode size | `[2028, 1520]` |
| Bayer / science shape | `[1520, 2032]` |
| RGB shape | `[1520, 2028, 3]` |
| Color depth | **12-bit** (`SBGGR12`) |
| Science dtype | `uint16` |
| Science filesize | 5.9 MiB |
| Preview filesize | 898.2 KiB |
| Requested exposure | 0.05 s / µs |
| Got exposure | 0.049992 |
| Exposure check | err=8 µs (0.016%) |
| AnalogueGain | `1.0` (req `1.0`) |
| ColourGains | R=`1.0` B=`1.0` |
| ScalerCrop | `[0, 0, 4056, 3040]` |
| FrameDuration | `50303` µs |
| Science mean | `3626.039701292478` |
| RGB mean | `190.12874320910757` |

### Timing

| Metric | Seconds |
|---|---|
| Requested exposure | 0.05 |
| Got exposure | 0.049992 |
| FrameDuration | 0.050303 |
| Acquire (single request) | 0.0986 |
| Acquire raw (legacy split) | n/a |
| Acquire RGB (legacy split) | n/a |
| Save science `.npy` | 0.0064 |
| Save preview BMP | 0.0583 |
| Processing total (suite path) | 0.1926 |
| Single-request capture | True |

### Framerate estimates

| Estimate | FPS | Period (s) | Meaning |
|---|-----|---|---|
| Exposure-limited max | 19.880 | 0.050303 | Cannot exceed 1/exposure (or FrameDuration) |
| Suite+disk observed | 5.192 | 0.1926 | This harness (raw+rgb+npy+bmp) |
| RAM science estimate | 10.142 | 0.0986 | Keep arrays in RAM, skip disk (production-like) |

### Files

- Science: [`frame_000_bayer.npy`](../cam_test_out/20260809T140213/bin2x2/frame_000_bayer.npy)
- Preview: [`frame_000_preview.bmp`](../cam_test_out/20260809T140213/bin2x2/frame_000_preview.bmp)
- Meta: [`frame_000_meta.json`](../cam_test_out/20260809T140213/bin2x2/frame_000_meta.json)
- Preset: [`preset.json`](../cam_test_out/20260809T140213/bin2x2/preset.json)

---

## `bin2x2_crop`

**PASS** — as expected

preview bin2x2_crop

| Field | Value |
|---|---|
| Acquisition mode | `bayer` + RGB preview |
| Sensor mode size | `[1332, 990]` |
| Bayer / science shape | `[990, 1344]` |
| RGB shape | `[990, 1332, 3]` |
| Color depth | **12-bit** (`SBGGR12`) |
| Science dtype | `uint16` |
| Science filesize | 2.5 MiB |
| Preview filesize | 890.7 KiB |
| Requested exposure | 0.05 s / µs |
| Got exposure | 0.049999 |
| Exposure check | err=1 µs (0.002%) |
| AnalogueGain | `1.0` (req `1.0`) |
| ColourGains | R=`1.0` B=`1.0` |
| ScalerCrop | `[696, 528, 2664, 1980]` |
| FrameDuration | `50208` µs |
| Science mean | `3602.7254644660893` |
| RGB mean | `177.33386189219522` |

### Timing

| Metric | Seconds |
|---|---|
| Requested exposure | 0.05 |
| Got exposure | 0.049999 |
| FrameDuration | 0.050208 |
| Acquire (single request) | 0.0338 |
| Acquire raw (legacy split) | n/a |
| Acquire RGB (legacy split) | n/a |
| Save science `.npy` | 0.003 |
| Save preview BMP | 0.0285 |
| Processing total (suite path) | 0.0785 |
| Single-request capture | True |

### Framerate estimates

| Estimate | FPS | Period (s) | Meaning |
|---|-----|---|---|
| Exposure-limited max | 19.917 | 0.050208 | Cannot exceed 1/exposure (or FrameDuration) |
| Suite+disk observed | 12.739 | 0.0785 | This harness (raw+rgb+npy+bmp) |
| RAM science estimate | 19.917 | 0.050208 | Keep arrays in RAM, skip disk (production-like) |

### Files

- Science: [`frame_000_bayer.npy`](../cam_test_out/20260809T140213/bin2x2_crop/frame_000_bayer.npy)
- Preview: [`frame_000_preview.bmp`](../cam_test_out/20260809T140213/bin2x2_crop/frame_000_preview.bmp)
- Meta: [`frame_000_meta.json`](../cam_test_out/20260809T140213/bin2x2_crop/frame_000_meta.json)
- Preset: [`preset.json`](../cam_test_out/20260809T140213/bin2x2_crop/preset.json)

---

## `crop`

**UNKNOWN** — ScalerCrop not visible in metadata

preview crop

| Field | Value |
|---|---|
| Acquisition mode | `bayer` + RGB preview |
| Sensor mode size | `[4056, 3040]` |
| Bayer / science shape | `[3040, 4064]` |
| RGB shape | `[1520, 2028, 3]` |
| Color depth | **12-bit** (`SBGGR12`) |
| Science dtype | `uint16` |
| Science filesize | 23.6 MiB |
| Preview filesize | 898.2 KiB |
| Requested exposure | 0.05 s / µs |
| Got exposure | 0.049963 |
| Exposure check | err=37 µs (0.074%) |
| AnalogueGain | `1.0` (req `1.0`) |
| ColourGains | R=`1.0` B=`1.0` |
| ScalerCrop | `[0, 0, 4056, 3040]` |
| FrameDuration | `85335` µs |
| Science mean | `3616.1508980489793` |
| RGB mean | `186.509863879373` |

### Timing

| Metric | Seconds |
|---|---|
| Requested exposure | 0.05 |
| Got exposure | 0.049963 |
| FrameDuration | 0.085335 |
| Acquire (single request) | 0.14 |
| Acquire raw (legacy split) | n/a |
| Acquire RGB (legacy split) | n/a |
| Save science `.npy` | 0.0287 |
| Save preview BMP | 0.0615 |
| Processing total (suite path) | 0.2803 |
| Single-request capture | True |

### Framerate estimates

| Estimate | FPS | Period (s) | Meaning |
|---|-----|---|---|
| Exposure-limited max | 11.719 | 0.085335 | Cannot exceed 1/exposure (or FrameDuration) |
| Suite+disk observed | 3.568 | 0.2803 | This harness (raw+rgb+npy+bmp) |
| RAM science estimate | 7.143 | 0.14 | Keep arrays in RAM, skip disk (production-like) |

### Files

- Science: [`frame_000_bayer.npy`](../cam_test_out/20260809T140213/crop/frame_000_bayer.npy)
- Preview: [`frame_000_preview.bmp`](../cam_test_out/20260809T140213/crop/frame_000_preview.bmp)
- Meta: [`frame_000_meta.json`](../cam_test_out/20260809T140213/crop/frame_000_meta.json)
- Preset: [`preset.json`](../cam_test_out/20260809T140213/crop/preset.json)

---

## `fast`

**PASS** — as expected

preview fast

| Field | Value |
|---|---|
| Acquisition mode | `bayer` + RGB preview |
| Sensor mode size | `[2028, 1520]` |
| Bayer / science shape | `[1520, 2032]` |
| RGB shape | `[1520, 2028, 3]` |
| Color depth | **12-bit** (`SBGGR12`) |
| Science dtype | `uint16` |
| Science filesize | 5.9 MiB |
| Preview filesize | 898.2 KiB |
| Requested exposure | 0.005 s / µs |
| Got exposure | 0.004996 |
| Exposure check | err=4 µs (0.080%) |
| AnalogueGain | `1.0` (req `1.0`) |
| ColourGains | R=`1.0` B=`1.0` |
| ScalerCrop | `[0, 0, 4056, 3040]` |
| FrameDuration | `22131` µs |
| Science mean | `774.8282457651264` |
| RGB mean | `92.56671240786878` |

### Timing

| Metric | Seconds |
|---|---|
| Requested exposure | 0.005 |
| Got exposure | 0.004996 |
| FrameDuration | 0.022131 |
| Acquire (single request) | 0.1011 |
| Acquire raw (legacy split) | n/a |
| Acquire RGB (legacy split) | n/a |
| Save science `.npy` | 0.0066 |
| Save preview BMP | 0.0624 |
| Processing total (suite path) | 0.1998 |
| Single-request capture | True |

### Framerate estimates

| Estimate | FPS | Period (s) | Meaning |
|---|-----|---|---|
| Exposure-limited max | 45.185 | 0.022131 | Cannot exceed 1/exposure (or FrameDuration) |
| Suite+disk observed | 5.766 | 0.173441 | This harness (raw+rgb+npy+bmp) |
| RAM science estimate | 9.891 | 0.1011 | Keep arrays in RAM, skip disk (production-like) |

Burst frames: **4**
Inter-frame mean/min/max: 0.17344146966934204 / 0.16029739379882812 / 0.2006211280822754 s
Approx FPS (manifest): **5.765633800880797**

### Files

- Science: [`frame_000_bayer.npy`](../cam_test_out/20260809T140213/fast/frame_000_bayer.npy)
- Preview: [`frame_000_preview.bmp`](../cam_test_out/20260809T140213/fast/frame_000_preview.bmp)
- Meta: [`frame_000_meta.json`](../cam_test_out/20260809T140213/fast/frame_000_meta.json)
- Preset: [`preset.json`](../cam_test_out/20260809T140213/fast/preset.json)

---

## How to reproduce

```powershell
powershell -File backapp/scripts/run_hq_cam_tests.ps1
python backapp/scripts/generate_hq_capability_report.py
```

Static camera notes: [`pi-hq-camera.md`](pi-hq-camera.md)

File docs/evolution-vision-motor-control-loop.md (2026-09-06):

# Evolution: camera ↔ motor autoguide loop

**Status:** plan only (no code in this change). Delivery is **phased A–H** (§11); timing gates are **Pi benches** (§10).  
**Audience:** next implementation pass on the Pi (`piscope`) + wasp UI.  
**Depends on:** current open-loop ASC/DEC path (`motorControl.py` → Pico 2 W) and HQ preview path (`cam_picamera2.py`).

This file is the evolution note for a closed control loop: keep a chosen star still on the IMX477 by trimming ASC and DEC rates. Polar alignment is *close*, not perfect, so DEC must move. ASC sidereal is *close* (−20 … −15 STEP/s; locked today at **−15.15**), not perfect, because of drivetrain / gear error.

The operator surface is a **second locator** (tracking lock), not a reuse of today’s composition mark. Geometry inputs (celestial DEC, focal length, ASC+/DEC+ on the chip) come from the UI and ride with the crop into a **dedicated guide worker**. That worker isolates the star on a small native ROI, converts pixel drift to on-sky angle, and emits rate trims. Camera acquisition, hub fan-out, and motor serial stay out of that hot path.

---

## 1. Why this exists

Today the stack is open-loop:

```text
UI slider / “sidereal”
        │  ctlparams {k: ASC|DEC|ASC_SIDEREAL, v: steps/s}
        ▼
rootserver  →  motorControl  →  Pico (dir + step_us)
```

`MountTracker` in [`backapp/motorControl.py`](../backapp/motorControl.py) only *integrates* the commanded rate. It does not look at the sky.

What we actually have:

| Fact | Consequence |
|---|---|
| Polar alignment is “close” | residual field drift has a DEC component; DEC cannot stay at 0 forever |
| ASC sidereal is empirical (−15.15 STEP/s, see [`backapp/asc_rates.py`](../backapp/asc_rates.py)) | mean rate is usable as **feedforward**, not as the whole answer |
| Gears / belt / worm are imperfect | periodic + slowly varying ASC error; PID on a star can trim it |
| Camera rotation vs mount axes is known *to the operator* | pixel `(u, v)` can be rotated into mount `(ASC, DEC)` once ASC+ / DEC+ are set on the tracking locator |
| Plant gain vs declination is *not* constant | same PID numbers, if they act on raw pixels, will be wrong as DEC changes |
| Plate scale depends on optics *and* binning | `f_mm` + `sensor_preset` must be in the loop, not a hidden constant only |

The first closed loop should be a **two-axis rate PID on one lock star**, sitting on top of the existing sidereal feedforward. Not plate-solving, not PEC tables, not multi-star guiding — those can come later.

---

## 2. Goal (v1)

Hold one operator-chosen star near a lock pixel by continuously adjusting motor *speeds*:

```text
ω_asc = ω_sidereal + Δω_asc_pid
ω_dec = 0          + Δω_dec_pid
```

- `ω_sidereal` stays the current empirical command (`ASC_SIDEREAL_UI_SPEED = -15.15`).
- PID outputs are **small trims** (tenths of a STEP/s), not a replacement for sidereal.
- DEC trim absorbs polar-alignment residual and slow flexure.
- ASC trim absorbs gear PE and the sidereal calibration leftover.

Success on sky: after lock, the guide star’s centroid stays inside a few pixels for minutes, without oscillating, at both mid-DEC and near the equator. Near the pole, ASC guide is allowed to go quiet (see §5).

Operator-visible success:

- A **tracking locator** (separate from the existing preview locator) marks the star being guided.
- The UI can show **which way ASC+ and DEC+ point** on that locator.
- A switch reveals the **small cropped native image** the algorithm actually uses, with the isolated star and a lightweight overlay (centroid, SNR, angular error, trims).

---

## 3. Assumptions we are taking as given

1. **Mount kinematics are equatorial and “close enough.”** Polar error is small compared with the FOV, but not zero. Hour-angle-dependent DEC drift is slow enough for an I-term.
2. **Camera ↔ mount orientation is operator-set in v1.** The tracking locator carries ASC+ and DEC+ directions on the chip (rotation + optional flips). That is a night-ops control, not an online estimator. A later pulse-ASC / pulse-DEC calibration can *fill* those fields; it does not replace them.
3. **Plate scale is computed from UI focal length + known pixel pitch + current binning.** IMX477 pitch is 1.55 µm ([`backapp/docs/pi-hq-camera.md`](../backapp/docs/pi-hq-camera.md)):

   ```text
   s_1x1_arcsec/px = 206.265 × 1.55 / f_mm
   s              = s_1x1 × bin   # bin = 1 for full / full_2160; 2 for bin2x2*
   ```

   `f_mm` is an editable UI field (propagate every lock / settings tick). It can still be refined later by “nudge ASC 1° and count pixels.”
4. **The operator points at the star** with the tracking locator (click and/or sliders). We do not need a catalog in v1.
5. **Celestial DEC of the lock is known to a few degrees** and is typed (or confirmed) in the UI. That is the `cos δ` input. Do **not** treat raw `newdecDeg` as celestial δ unless a park offset is set.
6. **Only the camera worker owns the IMX477.** Guiding must not open a second `Picamera2()`. Exclusive access is already documented in the HQ camera notes. The camera worker *crops*; it does not run PID.
7. **Pico rate changes are already ramped (~100 ms).** The guide loop should issue sparse setpoints, same as today’s UI, not pulse-level commands.
8. **Preview JPEG is display-only.** The loop never centroids the browser image or the hub JPEG.

---

## 4. The DEC-dependent plant (the part we do not want to retune by hand)

### 4.1 What actually changes with declination

On an equatorial mount, one extra ASC step rotates the polar axis by a fixed angle `Δα` (today ≈ `1 / ASC_STEPS_PER_DEGREE` ≈ 0.99″ at 1/8 microstep — see `asc_rates.py`).

The star’s **on-sky** displacement from that ASC step is

```text
Δθ_sky_from_asc = Δα · cos δ
```

| Where | `δ` | `cos δ` | ASC step → pixels |
|---|-----|---|---|
| Celestial equator | 0° | 1 | **maximum** |
| Mid-sky | ±45° | 0.71 | ~30% less |
| Near pole | ±80° | 0.17 | small |
| Pole | ±90° | 0 | **≈ 0** — ASC is invisible on the chip |

DEC steps do **not** pick up this `cos δ`. One DEC step is (to first order, small FOV) a constant on-sky angle, all night.

So: if the PID sees **pixel error** and outputs **ASC STEP/s**, the plant gain on ASC is proportional to `cos δ`. Tune it at the equator and it goes limp near the pole. Tune it near the pole and it oscillates at the equator.

DEC’s plant gain is roughly constant. DEC still needs its own PID because polar misalignment produces a real DEC drift; it just does not need the `cos δ` schedule.

### 4.2 Reconciling “zero at DEC zero / more at the equator”

Celestial **DEC = 0° is the equator** — that is where ASC motion on the chip is *largest*, not smallest.

If on the sky you saw “almost no star motion at DEC zero, much more toward the equator”, that almost certainly means **mount DEC-zero is a park / home near the pole**, and “going to the equator” is a large DEC slew from that home. The schedule below is in **celestial** `δ`. Map mount counts once:

```text
δ_celestial ≈ δ_park + sign · newdecDeg
```

Confirm the sign on the first night (slew DEC toward a known equatorial star; `newdecDeg` should move toward 0 celestial, not away).

v1 still **requires the operator to enter / confirm `δ` in the UI**. Mount-count mapping is a convenience fill, not the silent source of truth.

### 4.3 Recommended trick: do *not* retune Kp per DEC

Do not keep a table of PID gains vs DEC for v1. Normalize the error into **equivalent motor steps**, then run one PID:

```text
# pixel error in the native guide ROI (capture RGB, after binning)
e_u, e_v          [pixels, lock − current; sign: "where we want the star to go"]

# operator / locator orientation (constant until they change it)
[ e_asc_px ]     [  cosθ  sinθ ] [ e_u ]
[ e_dec_px ]  =  [ −sinθ  cosθ ] [ e_v ]     (+ ASC/DEC axis flips)

# plate scale from f_mm and current preset binning
e_asc_arcsec = e_asc_px · s(f_mm, bin)
e_dec_arcsec = e_dec_px · s(f_mm, bin)

# invert the plant so PID state is "steps of correction still needed"
cos_eff      = max(|cos δ|, cos_floor)          # see pole gate below
e_asc_steps  = e_asc_arcsec / (ASC_arcsec_per_step · cos_eff)
e_dec_steps  = e_dec_arcsec /  DEC_arcsec_per_step
```

Now both plants look like a simple integrator (speed error → position in steps). **One `(Kp, Ki, Kd)` pair per axis**, independent of DEC.

`ASC_arcsec_per_step` is already implied by `ASC_STEPS_PER_DEGREE` (3600 / 3626 ≈ 0.99″/step). DEC can start as the same number and be split later if the two gear trains differ.

The **angular** quantities `e_*_arcsec` (and their per-frame deltas) are what the UI overlay should show as “drift.” The PID still runs on `e_*_steps`.

### 4.4 Pole gate (do not divide by ~0)

When `|δ| > δ_freeze` (start at **80°**, `cos_floor ≈ 0.17`):

- keep using `cos_floor` in the divisor so numbers stay finite
- **freeze the ASC I-term** and scale ASC `Kp` down (or set `Δω_asc = 0`)
- leave the DEC loop running — DEC is still observable

ASC near the pole is barely visible in the image; cranking gain there only injects noise into RA.

### 4.5 If we ever want empirical schedules anyway

A 3-point table of *measured* `pixels_per_asc_step(δ)` (equator / 45° / 70°) can replace the analytic `cos δ` if the camera is slightly mis-rotated or the DEC axis is not a perfect polar. Fit `k · cos(δ − δ0)` rather than storing raw PID gains. Still convert to step-error before the PID.

---

## 5. Controller

### 5.1 Structure

Two independent PI-D (or PI) controllers after the rotation + step normalization:

```text
Δω_asc = sat( Kp · e_asc_px + Ki · I_asc )   # STEP/s per axis pixel (not e_*_steps)
Δω_dec = sat( Kp · e_dec_px + Ki · I_dec )

ω_asc_cmd = ω_ff_asc + Δω_asc
ω_dec_cmd = ω_ff_dec + Δω_dec
```

| Term | Role |
|---|---|
| Feedforward `ω_ff_asc` | empirical sidereal (−15.15). Operator can still nudge this. |
| Feedforward `ω_ff_dec` | 0, unless the UI is jogging DEC |
| P | kill the current offset (seeing + residual rate) |
| I | eat constant rate error: “sidereal is 0.3 STEP/s slow”, “polar error wants +0.05 STEP/s DEC” |
| D | optional, heavily low-pass; start at 0. Seeing will look like D-noise. |

Start **PI-only**. Do not ship a D term on night one. See §5.3–5.4.

### 5.2 Suggested starting limits (to be confirmed on sky)

These are *order-of-magnitude* so the first night cannot run away. Not final tunes.

| Parameter | Starting guess | Why |
|---|---|-----|
| Loop rate | 2–5 Hz | preview emit is already capped at 8 fps; seeing is faster than we can usefully chase. Processing budgets: §10 |
| ASC trim `Δω` | ±2 STEP/s | sidereal is ~15 STEP/s; gears should not need more |
| DEC trim `Δω` | ±1 STEP/s | polar residual should be small if alignment is “close” |
| Deadband | ~0.3–0.8 px (after a 3-frame centroid EMA) | do not chase seeing |
| I clamp | same as trim limits, anti-windup on sat | lost-star / slew must not wind I |
| Min command Δ | ~0.02 STEP/s | Pico `step_us` is integer; skip no-op writes |
| Lost-star | N=8 misses → hold last `Δω`, do not slam to 0 | then after T=5 s revert to feedforward only |

Derivative on a 3-sample EMA of the centroid, never on raw pixels.

### 5.3 Why PI, and why no D

The plant is already an integrator: we command **rate**, the star’s **position** is `∫ rate_error dt`. For that shape:

| Term | Fits this mount? |
|---|---|
| **P on position** | Yes. Offset decays. This is the main stabilizer. |
| **I on position** | Yes. Eats the biases we actually have (sidereal a bit wrong, polar-alignment DEC drift, a slow gear mean). |
| **D on position** | Not for v1. At 2–5 Hz, `d(centroid)/dt` is mostly **seeing**. Differentiating that makes the motors chase atmosphere and often tracks *worse* than open-loop sidereal. |

Commanding rate from position already uses the velocity channel. Extra D is “brake when the error is shrinking.” That only helps if the plant is laggy enough to overshoot **and** the velocity is clean. We have some lag (exposure + centroid + Pico’s ~100 ms ramp), but not a heavy current-loop servo.

**Add D later only if** a slow, clean overshoot remains after a 3-frame EMA — and then only on that filtered velocity, never on raw pixels. Prefer the drift-rate estimator in §5.4 before turning on `Kd`.

I is the term that can actually hurt: windup on a lost star or a slew. Clamp I to the trim limits and drop trim when the star disappears. That matters more than D.

CPU on the Pi is not the constraint. Isolation + PI on a 64–128 px tile is cheap next to JPEG encode. The constraints are **who owns the IMX477**, **not guiding from the browser JPEG**, and **not stalling capture / serial / hub** while we do it.

This is the same family as PHD2-style guiders (P / aggression + a slow bias), even when they do not call it PID.

### 5.4 Better methods — what is worth it later

Ranked for *this* mount, not in general:

| Priority | Method | When |
|---|---|---|
| v1 | **PI + sidereal feedforward + `cos δ` step-normalization** | First closed loop. Matching physics: integrator + constant bias + seeing. |
| Next, if I is ugly | **Drift-rate estimator, then P only** | Kalman or a slow EMA of centroid velocity. Treat estimated `ω_err` as extra feedforward; P only on leftover position. Same job as I, but the memory is a filtered rate, not an unbounded integral. Do this **before** adding `Kd`. |
| Cheap robustness | **Hysteresis / min-move** | Do nothing inside the deadband (seeing), then a proportional pulse. Can sit in front of the same PI. |
| After a working loop | **PEC** | Learn the worm/belt period on ASC. PID cannot memorize repeating PE; it only chases it. |
| Later SNR | **Multi-star / correlation** | Better measurement, same controller. Not a different philosophy. |

Usually **not** worth it here: MPC, LQR, Smith predictors, adaptive-gain PID tables. The `cos δ` normalization already does the one schedule that is physically real. Plate-solving every frame, or a full PHD2 calibration dance, is also not better for v1 — known camera-vs-axes rotation *is* that calibration.

### 5.5 What the loop is *not*

- Not a position goto. We command **rates**, same as today.
- Not PEC. Periodic gear error will be reduced, not memorized (until §5.4).
- Not field-rotation correction. One star cannot de-rotate the frame; polar error will still rotate the field slowly. That is acceptable for v1 (spectro / single-object work).

---

## 6. Star lock (sensing)

### 6.1 Two locators — do not overload the existing one

Today’s [`locator_*`](../backapp/cam_locator.py) is a **composition / aiming mark**: burned into the **preview JPEG only**, full-sensor normalized `(x, y)`, size scale, circle + cardinal ticks. It is *not* a lock, it does not name axes, and science Bayer is untouched. Keep it.

The autoguide loop needs a **tracking locator**, a different object:

| | Existing `locator_*` | New tracking locator (`track_*` names indicative) |
|--|---|---|
| Purpose | “where am I looking / framing” | “this star is the lock” |
| Drawn | burned into preview JPEG in the camera worker | **client overlay** (and optional crop JPEG from the guide worker) |
| Position | full IMX477 fractions `locator_x/y` | same coordinate space: full-sensor fractions `track_x/y` |
| Size | glyph radius | **ROI size** (how much native image to crop), plus a distinct glyph |
| Axes | none | **ASC+ and DEC+ directions** on the chip |
| When disabled | no red mark | no lock, no crop, no PID |

Why a second object:

- Operators still want the composition circle while guiding a different star (or while the lock is off).
- Burning the lock into the preview JPEG fights the “show me the work crop / overlay” requirement and couples display to sensing.
- Axis arrows would make the existing red glyph unreadable if we stuffed them into the same mark.

v1 lock gesture: **stay-where-placed**. Click on [`imgDisplay.vue`](../webapp/wasp/src/components/imgDisplay.vue) (it already computes normalized `(pixx, pixy)` and only `console.log`s them) *or* sliders/nudges, same pattern as the composition locator. Map the click from displayed JPEG pixels → full-sensor fractions using current `scaler_crop` / preview size (same math as `locator_preview_xy`, inverted). Optional later: “brightest blob near FOV center” if no click.

Hold-at-center (slew the star to chip center) is out of scope for the first loop.

### 6.2 Operator geometry fields (must reach the guide worker)

These are first-class UI + wire fields, not comments in a Pi config file:

| Field | Why |
|---|-----|
| `track_enabled` + `track_x` + `track_y` | lock position in full-sensor fractions |
| `track_roi` | crop half-size in **native capture pixels** after the current preset (start 32–64; UI slider) |
| `track_asc_dir` / `track_dec_dir` | which way is the **positive** ASC / DEC axis on the image (see §6.5) |
| `guide_dec_deg` | celestial `δ` for `cos δ` (editable; few degrees is enough) |
| `guide_focal_mm` | optics; plate scale with 1.55 µm pitch and current binning |

Changing `sensor_preset`, `scaler_crop`, or `preview_div` drops the lock (coordinate spaces moved) and requires a new placement. Changing `guide_dec_deg` / `guide_focal_mm` / axis dirs while locked **updates the geometry on the next sample** without unlocking — the star did not move on the chip.

### 6.3 Native crop (camera worker only copies pixels)

The loop must run on **capture RGB** (the array already in [`cam_picamera2.py`](../backapp/cam_picamera2.py) *before* `preview_div` JPEG), not on the hub JPEG and not in Vue.

Why:

- JPEG + WS + browser adds 100–300 ms and lossy ringing around stars
- `max_emit_fps` already drops frames when the hub is overwhelmed
- only one process may own the sensor
- binning and resolution are those of the **sensor preset + main RGB**, not of the downsampled preview

Per locked frame (or every Nth capture):

1. Map `track_x/y` from full-sensor fractions → **capture-RGB pixels** (account for `sensor_preset` size, `scaler_crop`, and that ScalerCrop metadata is in full-sensor space even when binned — same rules as the existing locator).
2. Center a square ROI of `track_roi` on the last known centroid (first frame: the lock pixel). Clamp to the RGB bounds; if the lock is outside the current crop, `ok: false`.
3. Copy that small tile (and a compact metadata blob) to the guide worker. Do **not** decode `srcimage` in a new process. Pattern: same idea as [`cam_storage.py`](../backapp/cam_storage.py) but the payload is tiny (e.g. 64×64×3 uint8 ≈ 12 KiB), so a **single shm slot or a multiprocessing queue of numpy copies** is enough. Do not ship the full frame.
4. Camera worker continues spectrum + JPEG + optional science Bayer on the **uncropped** path. Cropping must not add a second capture.

The worked image is always this small native tile. That is what makes isolation cheap and stable.

### 6.4 Star isolation (guide worker, every tile)

The star is **not** one pixel. The tile is noisy. Isolation runs every frame, so it must be a boring, stable estimator — not a clever re-acquisition.

Recommended v1 (all numpy, no OpenCV required):

1. Convert ROI to luminance (`0.3 R + 0.6 G + 0.1 B` or max of channels — pick one and freeze it in tests).
2. Background: local median (or 3σ-clipped mean of a border annulus). Subtract.
3. Gate: pixels above `max(k · σ_bg, floor)`. Reject the frame if too few pixels, too many (saturation / cloud / hot column), or peak in the outermost ring (star leaving).
4. **Intensity centroid** of the gated blob (first moment). Optional: one pass of windowed centroid around that peak so a nearby hot pixel does not steal the lock.
5. EMA (3 frames) of `(u, v)` before geometry. Deadband on the smoothed position.
6. `ok: false` on SNR / saturation / left-ROI. Do **not** jump to the brightest unrelated blob in the tile — that is how the lock walks to a neighbor.

Do **not** for v1: 2D Gaussian MLE, matched filter banks, multi-star, or “recenter on the max pixel.” Max-pixel is unstable on a several-pixel PSF plus read noise.

The lock pixel (where the tracking locator was placed) is the **setpoint**. The centroid is the **measurement**. Drift in the ROI is `centroid − lock` in capture pixels, then §4.3.

Synthetic tests (no camera): Gaussian PSF 2–4 px σ, Poisson + Gaussian noise, slow linear drift, a hot pixel, a second dimmer star at the edge. The estimator must stay on the primary and report `ok: false` when SNR collapses.

### 6.5 ASC+ / DEC+ on the tracking locator

Store as an operator-editable orientation, not a hidden `GUIDE_THETA_RAD` only:

```text
track_theta_deg     # image +u → ASC+  (0 = ASC+ points right on the capture RGB)
track_flip_asc      # 0|1  reverse ASC+ after rotation
track_flip_dec      # 0|1  reverse DEC+ after rotation
```

UI: two colored ticks/arrows on the tracking overlay (ASC+ vs DEC+). Discrete 90° rotate + flip buttons are enough for night ops; a free angle slider is optional. DEC+ should stay ~90° from ASC+; if the operator sets a non-orthogonal pair, v1 still uses one `θ` plus flips (document that). If a later calibration shows the axes are not 90°, replace `θ` with both columns of `R`.

Measure once when convenient: pulse ASC +N steps with DEC held; the star’s pixel track *is* ASC+ on the chip. Pulse DEC the same way. That can *write* `track_theta_deg` / flips; the UI remains the source of truth so a 180° camera rotation is a click, not a Pi redeploy.

Signs must be proven on hardware once and then frozen in tests with synthetic tracks. `DIR_INVERT_*` in [`pico_motor.py`](../backapp/pico_motor.py) is a *motor* flag; guide rotation is the *on-sky after those flags* result.

### 6.6 Samples the rest of the stack consumes

Guide worker emits a small `guideSample` / `guideInfo` (not a full frame) at loop rate:

```json
{
  "msgtype": "guideSample",
  "t": 1710000000.12,
  "ok": true,
  "u": 32.4,
  "v": 31.1,
  "lock_u": 32.0,
  "lock_v": 32.0,
  "roi_origin_u": 980,
  "roi_origin_v": 726,
  "snr": 18.2,
  "e_asc_arcsec": 0.41,
  "e_dec_arcsec": -0.12,
  "e_asc_steps": 0.48,
  "e_dec_steps": -0.12,
  "dAsc": -0.07,
  "dDec": 0.02,
  "dec_deg": 42.0,
  "focal_mm": 400,
  "preset": "bin2x2",
  "bin": 2
}
```

`u,v` here are **ROI-local** (small image coordinates). Full-chip position is `roi_origin + (u, v)` for the preview overlay.

Optional, gated by a UI switch (`guide_show_crop`): a **second, small JPEG** of the worked tile with centroid crosshair (encode in the guide worker, not the camera worker). Broadcast only when the switch is on so the hub is not paying for two JPEGs all night.

---

## 7. Where the loop lives in *this* repo

Do not put the PID in the browser. Do not give the guide process a second camera handle. Do not let UI sliders and the PID fight over the same absolute `ASC`/`DEC` setpoint. Do not run isolation inside the camera capture loop or the motor serial loop.

### 7.1 Preferred layout: dedicated guide worker

v1 **picks the dedicated service** (`guideControl.py` + systemd unit, e.g. `astroscop-guide`).

Earlier drafts preferred PID inside the motor worker. That stays a valid fallback, but it couples three different clocks (centroid, PI, Pico UART) and makes the crop-preview encode a motor-process problem. Isolation + geometry + PI + optional crop JPEG is enough work and enough failure domain to stand alone — same reason science Bayer already left the camera process via [`cam_storage.py`](../backapp/cam_storage.py).

```text
                    full RGB (camera owns IMX477)
   cam_picamera2 ──► crop native ROI ──► shm / queue ──► guideControl
         │                                              │
         │ JPEG preview                                 │ guideSample + trims
         ▼                                              │ optional crop JPEG
    rootserver hub ◄────────────────────────────────────┘
         │
         ├──► wasp (overlays, crop switch, DEC, f_mm, axis dirs)
         └──► motorControl  (mixer: ω = ω_ff + Δω_guide)
                    │
                    ▼
                  Pico
```

| Process | Owns | Must not own |
|---|---|---|
| `cam_picamera2` | IMX477, full RGB, Bayer shm, preview JPEG, **ROI copy** | PID, star isolation, crop JPEG for UI |
| `guideControl` (new) | isolation, `guide_geom`, PI, `GUIDE_DASC/DDEC`, optional crop JPEG, `guideInfo` | Picamera2, Pico serial, hub listen sockets beyond its client WS |
| `motorControl` | Pico, **rate mixer**, `motorInfo` | pixels |
| `rootserver` | fan-out | computation |

Restart domains: camera hang still systemd-restarts only the camera (today). Guide crash must **drop trims** (motor sees silence / `ok` timeout → feedforward only), not take down capture. Motor crash must not unlock the camera.

Hub changes in [`rootserver.py`](../backapp/rootserver.py):

- fan-out tracking-locator / DEC / `f_mm` / axis dirs to camera (for crop) **and** guide (for geometry)
- camera → guide: not via the browser; either a dedicated WS client from `guideControl` to the hub, or a localhost socket / shm metadata channel. Prefer **hub WS** so there is one debug path, but the **pixel tile must not go through the UI**.
- fan-out `GUIDE_DASC` / `GUIDE_DDEC` to the motor socket
- broadcast `guideInfo` (+ optional crop JPEG) to wasp

Camera worker stays the *only* place that touches the sensor. Guide worker is the *only* place that isolates the star and runs PI.

### 7.2 Rate mixer (motor worker) — required

[`motorControl.py`](../backapp/motorControl.py) today treats `ctlparams ASC` / `DEC` as **absolute** speeds. Guiding needs a mixer:

```text
commanded = feedforward  +  guide_trim
```

New `ctlparams` keys (names indicative):

| Key | Who sends it | Meaning |
|-----|---|---|
| `ASC` / `DEC` | UI | **feedforward** while guiding is armed; absolute if guiding is off (today’s behavior) |
| `ASC_SIDEREAL` | UI | set ASC feedforward to −15.15 |
| `GUIDE_ENABLE` / `GUIDE_DISABLE` | UI | arm mixer |
| `GUIDE_DASC` / `GUIDE_DDEC` | **guide worker** | trims (STEP/s). Ignored if not enabled or star lost past timeout |
| tracking locator / `GUIDE_LOCK` / `GUIDE_UNLOCK` | UI | forwarded to camera (crop on/off) and guide (PI reset) |

`motorInfo` grows: `guideEnabled`, `dAsc`, `dDec`, `ffAsc`, `ffDec`, so the sliders can keep showing the *operator* feedforward while the Pico runs the sum.

When the operator disarms motors or hits axis stop/reset: drop trims, freeze I-terms, unlock.

The motor worker does **not** subscribe to pixel tiles. It only applies trims it is given.

### 7.3 UI (wasp)

Night-operable, next to [`stepperControl.vue`](../webapp/wasp/src/components/stepperControl.vue) and [`captureOptions.vue`](../webapp/wasp/src/components/captureOptions.vue). Do **not** hide or reuse the existing locator panel.

**Tracking locator panel (new):**

- enable / unlock
- X/Y (full-sensor fractions) + nudge, same UX family as the composition locator but a different glyph (e.g. box or diamond, not the red circle)
- ROI size
- ASC+ / DEC+ rotate 90° and flip; overlay arrows on the preview
- **DEC (deg)** — this *is* the `cos δ` input; pre-fill from mount+park if we have it, always editable
- **focal length (mm)** — plate scale; persist in the client like other camera fields
- **Guide enable** (requires motor arm + Pico linked + tracking locator on + star `ok`)
- **Show work crop** switch — when on, `imgDisplay` (or a sibling overlay) shows the small native JPEG from the guide worker instead of / on top of the full preview; star mark + SNR / `e_asc_arcsec` / `e_dec_arcsec` / `Δω` as text overlay. Prefer a **dedicated HTML overlay** on the existing preview (`imgDisplay.vue`) rather than burning marks in the camera JPEG, so composition locator and tracking overlay can coexist.

**Readouts:** lock SNR, `e_asc_px` / `e_dec_px`, angular error, `Δω_asc` / `Δω_dec`, `cos δ`, lost-star banner.

Do not hide the ASC/DEC sliders. They remain the feedforward (sidereal + jog). While guiding, moving a slider changes `ω_ff`, not a fight with the PID.

Click-to-place: wire `imgClicked` to the tracking locator when that tool is armed; do not steal clicks from the composition locator when only that one is enabled.

---

## 8. Geometry cheatsheet (implementation)

Signs must be proven on hardware once and then frozen in tests with synthetic tracks.

```text
sky, small FOV, camera aligned after R:

  d(u,v)/dt  ≈ s(f_mm, bin)⁻¹ · R · [  (ω_asc_err · cos δ)  ]
                                    [   ω_dec_err           ]

ω_*_err = commanded_rate − true_sky_rate   [STEP/s]
```

Polar misalignment adds a slowly varying `ω_dec_true ≠ 0` and a tiny extra ASC term. The I-terms eat the mean of that. We do not model the full alignment matrix in v1.

Hour angle does **not** change the `cos δ` factor. It *does* change polar-error DEC drift; that is why DEC has an I-term rather than a one-shot offset.

Binning: `u,v` and ROI size are in **capture RGB pixels**. `s` must use the same bin factor as that array (`1` or `2` for current presets). Mixing preview_div pixels into `s` is a bug.

---

## 9. Safety and night-ops behavior

- Guiding never enables drivers by itself. Motor arm + Pico link stay as they are.
- Lost star / `ok: false`: hold last trim briefly, then feedforward-only. Do not command a search slew in v1.
- Exposure / preset change (`sensor_preset`, `scaler_crop`, `preview_div`): drop lock (coords are in a different space) and require a new placement.
- Science save can keep running; the crop is a copy of RGB the preview already has. Do not add a second capture.
- Clamp every command through the existing `speed_to_dir_step_us` limits (50 µs … 10 s).
- Guide worker silence (crash, blocked): motor times out trims the same as lost-star.
- Log `δ`, `f_mm`, `bin`, `cos_eff`, `e_*_arcsec`, `e_*_steps`, `Δω_*` at ~1 Hz for the first on-sky nights.

---

## 10. Performance budgets

The loop is **2–5 Hz** (§5.2). Seeing is faster than that; we do not chase it. Every added stage must leave the camera JPEG path and the Pico serial path alone.

Budgets are **p95 wall time on the Pi**, measured there. A laptop number is a smoke check only — ARM vs x86, numpy/OpenBLAS, and thermal throttling all lie. If a bench misses the gate, the phase is not done.

| Stage | p95 gate (Pi) | Why that number |
|---|---|---|
| Geometry (`pixels_to_axis_steps` + pole gate) | **< 0.5 ms** | trivial; catch accidental Python loops |
| Star isolation on 64×64 RGB | **< 5 ms** | 5 Hz = 200 ms period; isolation must be noise |
| Star isolation on 128×128 RGB | **< 15 ms** | upper ROI we will allow in v1 |
| ROI extract (copy from capture RGB) | **< 2 ms** (64²), **< 5 ms** (128²) | runs *in* the camera worker; must not delay JPEG/spectrum |
| Handoff camera → guide (queue/shm + metadata) | **< 3 ms** extra in the camera process | decoupling is the point |
| PI both axes, one sample | **< 0.5 ms** | rounding error next to isolation |
| Optional crop JPEG encode (128², quality ~70) | **< 15 ms** | **only when UI switch is on**; never on the capture thread |
| Guide worker: tile in → `guideSample` + trims out (JPEG off) | **< 20 ms p95**, **< 50 ms max** | comfortably inside 5 Hz; 2 Hz still fine if we skip frames |
| Sustained | **≥ 5 Hz** for 30 s on synthetic 64², no growing backlog | drop/skip policy if the camera is faster |
| Mixer apply | no extra pixel work; same Pico write path as today | regression: disarm ≡ old behaviour |

Capture-path regression (live camera, Phase D): with tracking crop **on**, preview emit fps and capture `frame_time_ms` stay within **10%** of the same run with crop **off** (same preset, same shutter). Do not accept a design that steals the 8 fps emit budget.

JPEG crop for the UI is **opt-in** and encoded in the guide worker. Measuring that path with the switch off is a failed bench setup.

### 10.1 Where benches run

| Kind | Host | Role |
|---|---|---|
| Correctness unit tests (`test_guide_*.py`, mixer, hub) | **dev machine** (Windows/laptop) every phase | merge gate |
| Timing / throughput benches (`*_bench.py`) | **Pi only** is authoritative | phase gate for §10 table |
| Live camera crop / emit regression | **Pi**, `astroscop-camera` **stopped** (same rule as [`test_cam_settings_bench.py`](../backapp/test_cam_settings_bench.py)) | Phase D |
| On-sky closed loop | **Pi + mount + sky** | last phase; not a CI bench |

Benches are **pushed to the Pi and executed there**, then results pulled back — same family as [`scripts/run_cam_settings_bench.ps1`](../backapp/scripts/run_cam_settings_bench.ps1) (scp modules → `ssh` python → scp `/tmp/...` → local report). Expected new artifacts when those phases are coded (names indicative):

- `backapp/test_guide_geom_bench.py`
- `backapp/test_guide_isolate_bench.py`
- `backapp/test_guide_crop_bench.py` (live RGB crop + emit regression)
- `backapp/test_guide_worker_bench.py` (process loop, JPEG on/off)
- `backapp/scripts/run_guide_bench.ps1` (sync + run + pull)
- `backapp/docs/guide-bench-report.md` (latest PASS/FAIL vs the table above)

**Pi access** (SSH host alias, remote `backapp` path, which user, how to stop `astroscop-camera` / later `astroscop-guide`) is **not** copied here. It will be written into the bench script comment + that phase’s implementation notes, using the same `ASTROSCOP_PI_HOST` / deploy conventions as the camera benches. Do not invent a second way to reach the Pi.

Each bench must print p50/p95/max, iteration count, tile size, and **PASS/FAIL against the gate**. A report that only dumps milliseconds without a gate is incomplete.

---

## 11. Phased delivery

Docs-only until a phase is scheduled. **One phase per implementation pass.** Each phase is mergeable, has a regression net, and does not require the sky until the last one.

Rules:

- Do not start phase *N+1* until phase *N* tests are green **and** that phase’s Pi bench (if it has one) is PASS.
- Default production path stays **guide off** until the UI arm + mixer enable of the late phases.
- Do not put isolation or PID into `cam_picamera2` or `motorControl` “just for a prototype.”
- Names below are indicative; keep contracts stable once Phase A has shipped.

```text
A mixer/contracts → B geom → C isolate+ROI → D camera crop handoff
                                              ↘
                                               E guide worker + PI (synthetic tiles until D)
                                              ↙
                               G UI overlay ← F hub fan-out
                                              ↓
                               H arm mixer + on-sky
```

| Phase | What ships | Sky? | Camera? | Pi bench? |
|---|---|---|---|---|
| **A** | Wire shapes + motor mixer | no | no | no (correctness only) |
| **B** | `guide_geom.py` | no | no | yes — geom µs |
| **C** | ROI map + star isolation (pure) | no | no | yes — isolation ms |
| **D** | Camera copies native ROI off-process | no | **yes** (bench) | yes — crop + emit regression |
| **E** | `guideControl` + PI, synthetic in | no | no | yes — worker loop |
| **F** | Hub fan-out (lock / sample / trim) | no | optional | no (hub tests on laptop; smoke on Pi) |
| **G** | wasp tracking locator + overlay + crop switch | no motors | optional live preview | crop-JPEG encode in worker bench |
| **H** | Arm mixer from UI; on-sky bring-up | **yes** | yes | reuse E/D benches; no new gate |

Phases **D** and **E** can overlap on the branch (different files) but **E must run against a fake tile source until D’s handoff exists**. Do not block PI unit tests on a live IMX477.

---

### Phase A — contracts and mixer

**Goal:** Guiding can be *wired* without changing open-loop night ops.

**Code:**

- `ctlparams` keys + `motorInfo` / `guideInfo` / `guideSample` / `track_*` / `guide_dec_deg` / `guide_focal_mm` in [`ws_messages.py`](../backapp/ws_messages.py) (and wasp `messages.js` / `cameraSettings.js` as needed — wasp can wait until G if the hub still ignores unknown keys; prefer adding fields once).
- Motor mixer: `commanded = ff + trim`. Guide disabled (or no trims) ≡ today’s `ASC`/`DEC`.
- Stop / disarm / axis reset clears trim and ignores further `GUIDE_D*` until re-enabled.
- Missing `guideSample` / trim timeout → feedforward only.

**Tests (laptop):**

- Mixer: `ff + trim`, sat, enable off ignores trim, timeout, disarm.
- Regression: [`test_pico_motor.py`](../backapp/test_pico_motor.py) + [`test_rootserver_hub.py`](../backapp/test_rootserver_hub.py) still pass with new keys ignored or round-tripped.
- Composition `locator_*` settings tests unchanged ([`test_cam_locator.py`](../backapp/test_cam_locator.py)).

**Pi bench:** none. Mixer is not the timing risk.

**Done when:** with `GUIDE_ENABLE` unset, a Pi motor session behaves as today. Unit tests green on the laptop.

**Not in this phase:** pixels, UI lock, systemd unit.

---

### Phase B — geometry module

**Goal:** One function the rest of the stack can trust for `cos δ` and plate scale.

**Code:** [`backapp/guide_geom.py`](../backapp/guide_geom.py)

Frozen API:

- `plate_scale_arcsec_per_px(f_mm, bin)` (alias `plate_scale`) — `206.265 × 1.55 / f_mm × bin`
- `bin_factor_for_preset(preset)` — `full` / `full_2160` → 1; `bin2x2*` → 2
- `pixels_to_axis_steps(e_u, e_v, *, f_mm, bin, dec_deg, theta_deg=0, flip_asc=False, flip_dec=False)` → `AxisError` (`e_*_px`, `e_*_arcsec`, `e_*_steps`, `cos_eff`, `pole_gate`)
- `axis_steps_to_pixels(...)` — inverse, same kwargs
- θ = 0: ASC+ = `+u`, DEC+ = `+v` on capture RGB; then flips
- `DEC_ARCSEC_PER_STEP = ASC_ARCSEC_PER_STEP` (`3600 / ASC_STEPS_PER_DEGREE`) until a DEC pulse splits them
- `f_mm <= 0` or `bin` not in `{1, 2}` → `ValueError`
- Pole gate is a **flag**, not a trim: `|δ| > 80°` → `pole_gate=True`, still finite `e_asc_steps` via `cos_eff = max(|cos δ|, cos 80°)`; Phase E freezes ASC I / zeros `Δω_asc`

**Tests (laptop):** [`backapp/test_guide_geom.py`](../backapp/test_guide_geom.py)

- δ = 0°, 45°, 80°, 89°: same on-sky error → ASC step-error grows as `1/cos_eff`; DEC step-error stays flat; 89° `pole_gate` and finite ASC steps
- `bin=1` vs `bin=2`; two `f_mm`; flips reverse the matching axis only; roundtrip
- `f_mm <= 0` / bad bin raise

**Pi bench:** [`backapp/test_guide_geom_bench.py`](../backapp/test_guide_geom_bench.py) — 10k calls, p95 **< 0.5 ms**. Runner: [`backapp/scripts/run_guide_bench.ps1`](../backapp/scripts/run_guide_bench.ps1) (`ssh piscope`, remote `/home/fanf/astroScop/backapp`; geom stage does **not** stop `astroscop-camera`). Report: [`backapp/docs/guide-bench-report.md`](../backapp/docs/guide-bench-report.md).

**Done when:** tests green locally; Pi bench PASS in the report.

**Not in this phase:** isolation, camera, PID.

---

### Phase C — native ROI mapping + star isolation (no camera process)

**Goal:** Stable centroid on a noisy, multi-pixel star, and correct crop coordinates.

**Code:**

- [`backapp/guide_roi.py`](../backapp/guide_roi.py) — `lock_to_roi` / `lock_to_rgb_uv`. Full-sensor fractions + `scaler_crop` + RGB size → square tile. Reuses [`parse_scaler_crop`](../backapp/cam_locator.py) / `FULL_SENSOR_WH`. **Does not** clamp out-of-crop locks (that is the composition glyph). `track_roi` is half-size; tile is `2 * roi_half`, shifted to stay in-bounds.
- [`backapp/guide_isolate.py`](../backapp/guide_isolate.py) — `isolate_star`, `CentroidEma(n=3)`, `TileStack` (5-frame median of the native RGB tile before isolate):
  - luminance `0.3 R + 0.6 G + 0.1 B`
  - 3-px border-annulus median / σ
  - gate `max(3σ, 1)`
  - intensity first-moment **in a window around the lock** (not global max); if the lock window is empty, a short search around the lock recenters
  - `ok: false` on too few gated px, **sky** annulus too full, low SNR, peak in the outer ring — clipped star cores are kept
- Deadband stays Phase E. No geom/PID here.

**Tests (laptop, synthetic tiles):** [`test_guide_roi.py`](../backapp/test_guide_roi.py), [`test_guide_isolate.py`](../backapp/test_guide_isolate.py)

- Gaussian PSF 2–4 px σ + Poisson/read noise; slow drift; lock holds.
- Hot pixel and a dimmer neighbor at the tile edge must **not** steal the lock.
- Lost-star when SNR collapses or the blob hits the outer ring.
- ROI clamp when the lock is near the RGB border; lock outside crop → `ok: false`.

**Pi bench:** [`test_guide_isolate_bench.py`](../backapp/test_guide_isolate_bench.py) — 64² (p95 **< 5 ms**) and 128² (p95 **< 15 ms**), several SNR levels. No Picamera2; do not stop `astroscop-camera`. `run_guide_bench.ps1 -Stage isolate`. Report merges into [`guide-bench-latest`](../backapp/docs/guide-bench-latest/) so geom PASS is kept.

**Done when:** tests green locally; isolate section in [`guide-bench-report.md`](../backapp/docs/guide-bench-report.md) is PASS from `piscope` / `aarch64`.

**Not in this phase:** copying live frames, JPEG, PI, UI.

---

### Phase D — camera worker ROI handoff

**Goal:** The IMX477 owner extracts a small native RGB tile without running isolation, and without regressing preview timing.

**Code:**

- [`backapp/guide_handoff.py`](../backapp/guide_handoff.py) — `extract_guide_tile` (lock-centered `np.copy`) + `GuideTileSlot` **latest-wins shm** (max 128²). Not a `multiprocessing.Queue` (guide is a sibling systemd unit).
- [`CameraSettings`](../backapp/cam_settings.py) **output** fields: `track_enabled` (default false), `track_x/y`, `track_roi` half-size 8–64. No θ / DEC / `f_mm` on the camera.
- [`cam_picamera2.emit_frame`](../backapp/cam_picamera2.py): if tracking on, extract + slot write on the **capture** path. Off path: boolean check + close slot if it was open. No isolate, PID, or crop JPEG.

**Tests (laptop):** [`test_guide_handoff.py`](../backapp/test_guide_handoff.py) — origin vs `lock_to_roi`, outside crop → no tile, shm roundtrip + overwrite, disabled does not allocate, settings ingest.

**Pi bench (live camera, service stopped):** [`test_guide_crop_bench.py`](../backapp/test_guide_crop_bench.py) via `run_guide_bench.ps1 -Stage crop`.

- extract p95 **< 2 ms** (64²), **< 5 ms** (128²); handoff extra **< 3 ms**
- crop-on `frame_time_ms` / emit fps within **10%** of crop-off

**Done when:** laptop tests green; crop section in [`guide-bench-report.md`](../backapp/docs/guide-bench-report.md) PASS from `piscope`.

**Not in this phase:** systemd guide unit, UI, motors, isolate-in-camera.

---

### Phase E — guide worker + PI

**Goal:** A process that turns tiles into trims, fast enough, crash-isolated.

**Code:**

- [`backapp/guide_pid.py`](../backapp/guide_pid.py) — PI-only (`Kd=0`), `Kp=0.4`, `Ki=0.05`, sat ±2/±1, 0.5 px deadband, I anti-windup, pole-gate zeros ASC, lost-star hold 8 samples then drop after 5 s
- [`backapp/guide_process.py`](../backapp/guide_process.py) — `GuideEngine.process_tile`: isolate → EMA → geom → PI → `GuideSample`. Skip unchanged `seq`. `f_mm<=0` refuses
- [`backapp/guideControl.py`](../backapp/guideControl.py) — shm attach or `--feed synthetic`, ~5 Hz. **`--emit-trims` default off** (no Pico). JPEG off unless `--jpeg`
- [`backapp/deploy/astroscop-guide.service`](../backapp/deploy/astroscop-guide.service) — copied by install, **not enabled**

**Tests (laptop):** [`test_guide_pid.py`](../backapp/test_guide_pid.py), [`test_guide_process.py`](../backapp/test_guide_process.py)

**Pi bench:** [`test_guide_worker_bench.py`](../backapp/test_guide_worker_bench.py) — synthetic 64², **do not** stop the camera. `run_guide_bench.ps1 -Stage worker`. Gates: tile→sample p95 **< 20 ms**; JPEG-on p95 **< 15 ms**; 5 Hz 30 s and 10 Hz with **no backlog**.

**Done when:** tests green; worker section PASS on `piscope`.

**Not in this phase:** wasp overlay, hub `/guide` path, `GUIDE_ENABLE` from UI.

---

### Phase F — hub fan-out

**Status:** implemented. Tiles stay on shm. Control/status on WebSocket. `astroscop-guide` stays **disabled**; `--emit-trims` default off.

**Code:** [`rootserver.py`](../backapp/rootserver.py), [`guideControl.py`](../backapp/guideControl.py), [`cam_settings.py`](../backapp/cam_settings.py)

- Same validated `params` → camera (crop) **and** `/guide` (geometry)
- `GUIDE_D*` `ctlparams` from the guide socket → motor (mixer still needs `GUIDE_ENABLE`)
- `guideInfo` / `guideSample` → UI after stripping `jpeg` / `imageData` / `tile`
- Guide worker is a hub client at `ws://127.0.0.1:8765/guide`

**Tests (laptop):** [`test_rootserver_hub.py`](../backapp/test_rootserver_hub.py) `test_guide_hub_fanout`

**Pi bench:** none.

**Done when:** hub tests green.

**Not in this phase:** night-operable Vue; enabling the guide unit.

---

### Phase G — UI (tracking locator, overlay, work-crop switch)

**Status:** implemented. Mixer stays off (no `GUIDE_ENABLE` control). `astroscop-guide` stays disabled.

**Code:**

- [`guidePanel.vue`](../webapp/wasp/src/components/guidePanel.vue) — lock, ROI, 90°+flips, DEC, `f_mm`, show-crop; composition locator unchanged
- [`imgDisplay.vue`](../webapp/wasp/src/components/imgDisplay.vue) — HTML overlay (box + ASC+/DEC+ arrows); click-to-place when armed; crop inset
- [`trackOverlay.js`](../webapp/wasp/src/ws/trackOverlay.js) — invert `locator_preview_xy` + `object-fit: contain` click map
- Hub: `guideInfo.data.jpeg` (string) is forwarded; `tile` still stripped
- [`guideControl.py`](../backapp/guideControl.py) attaches base64 JPEG when encoding

**Tests:** `python test_cam_locator.py` invert; `test_rootserver_hub.py` jpeg-keep/tile-strip; `npm run test:overlay` in wasp.

**Pi bench:** none required.

**Done when:** overlay + composition locator are independent; crop inset works when the guide worker is running.

**Not in this phase:** claiming on-sky tracking success; mixer arm.

---

### Phase H — arm mixer and on-sky bring-up

**Status:** wiring implemented. Mixer defaults off. No sky simulator; on-sky steps are night notes (`ssh piscope`).

**Code:**

- [`astroscop-guide.service`](../backapp/deploy/astroscop-guide.service) — enabled on install; `--emit-trims` (mixer still ignores until `GUIDE_ENABLE`)
- [`motorControl.py`](../backapp/motorControl.py) — `GUIDE_ENABLE` only if UI armed **and** Pico linked
- Hub forwards `GUIDE_ENABLE`/`DISABLE` to `/guide` as well as motor; [`GuideEngine.reset()`](../backapp/guide_process.py) on those keys and on `track_enabled` falling
- wasp **Guide enable** gated by arm + Pico + lock + `ok` + `f_mm>0`; auto-disable if a gate drops
- ~1 Hz journal log: δ, f_mm, bin, cos_eff, e_arcsec, e_steps, Δω, ok

**Tests (laptop):** hub fan-out of `GUIDE_ENABLE` to motor+guide; `guideEnable.test.js` gate matrix.

**Pi indoor smoke (not a tracking PASS):** lock a lamp/LED; crop + `ok` without enable. If Pico linked: arm, enable, `systemctl kill astroscop-guide` → trims expire ~5 s.

**Night notes (deferred):** pulse ASC for arrows; mid-DEC / equator / high-DEC; crop vs full frame. Log δ, e_arcsec, Δω — do not file as a fake bench PASS.

**Not in this phase:** claiming on-sky success; sky simulator.

---

### Suggested implementation order (when we start)

Work **A → B → C** entirely on the laptop (plus B/C Pi benches once Pi access is written down). Then **D** (needs the camera) and **E** (needs the Pi for the worker bench, not the sky). **F** and **G** can proceed against a fake `guideInfo` if the hub contract from A/F is stable. **H** last.

If a phase is too large for one PR, split **inside** the phase (e.g. E: PID module + tests, then process + bench) but do not skip that phase’s Pi gate.

---

## 12. What we are explicitly not doing in v1

- Plate-solving / astrometry.net
- Multi-star / PHD2-style calibration dance (the locator `θ` + `cos δ` replaces most of that)
- PEC curve recording
- Autofocus / rotator
- Guiding from Bayer science frames (native **RGB** ROI is enough; science stays for Siril)
- A second process opening the HQ camera
- Per-DEC PID gain files
- Reusing or extending the existing burned-in `locator_*` glyph as the lock
- Running isolation or PID inside `cam_picamera2` or `motorControl`
- Centroiding the browser JPEG

---

## 13. Open items to settle on the first implementation PR

1. **Celestial δ source of truth** — typed DEC vs mount-count + park offset. Need one config key for the park; UI still confirms.
2. **DEC arcsec/step** — copy ASC’s 0.99″/step or measure with a DEC pulse.
3. **Pixel path camera → guide** — **decided (Phase D):** latest-wins `shared_memory` slot (`astroscop-guide-tile`), not a Queue. Queue cannot cross sibling systemd units.
4. **Hub vs localhost** — **decided (Phase F):** guide worker is a hub WS client on `/guide`. Control messages and sanitized `guideInfo` go through the hub; **tiles must not be base64 through wasp** (stripped + shm).
5. **Whether DEC gear train matches ASC** — if DEC `steps_per_degree` is wildly different, it only changes `DEC_arcsec_per_step`, not the PID structure.
6. **Sign of `DIR_INVERT_*` vs sky** — already flags in [`pico_motor.py`](../backapp/pico_motor.py); guide rotation must use the *on-sky* result after those flags.
7. **Default `guide_focal_mm`** — **18 mm** (this OTA); empty/zero still refuses to arm (plate scale undefined).
8. **Axis UI granularity** — 90° steps + flips vs continuous `θ`. Start with 90° + flips if the camera is square-on to the mount; add free `θ` if the first pulse test is clearly diagonal.
9. **Bench script host details** — filled: `ssh piscope`, remote `/home/fanf/astroScop/backapp`, user `fanf` (same as [`run_cam_settings_bench.ps1`](../backapp/scripts/run_cam_settings_bench.ps1)). Geom/isolate benches do not stop the camera; crop bench (Phase D) still must.

---

## 14. Pointers into the current tree

| Piece | Path | Role in this evolution |
|---|---|---|
| Sidereal feedforward | [`backapp/asc_rates.py`](../backapp/asc_rates.py) | `ω_ff_asc`; `ASC_STEPS_PER_DEGREE` → arcsec/step |
| Guide geometry | [`backapp/guide_geom.py`](../backapp/guide_geom.py) | plate scale, `cos δ`, pole gate, pixel ↔ step error |
| Guide ROI map | [`backapp/guide_roi.py`](../backapp/guide_roi.py) | full-sensor lock → capture-RGB tile (no out-of-crop clamp) |
| Guide isolation | [`backapp/guide_isolate.py`](../backapp/guide_isolate.py) | lock-window centroid + 3-frame EMA |
| Guide handoff | [`backapp/guide_handoff.py`](../backapp/guide_handoff.py) | lock-centered RGB copy + shm latest-wins |
| Guide PI | [`backapp/guide_pid.py`](../backapp/guide_pid.py) | PI trims on step-error (`Kd=0`) |
| Guide worker | [`backapp/guideControl.py`](../backapp/guideControl.py) | isolate + geom + PI; trims default off |
| Rate → Pico | [`backapp/pico_motor.py`](../backapp/pico_motor.py) | unchanged protocol; mixer sits above it |
| Motor worker | [`backapp/motorControl.py`](../backapp/motorControl.py) | mixer **only** (not PID) |
| Camera worker | [`backapp/cam_picamera2.py`](../backapp/cam_picamera2.py) | native RGB ROI copy; no isolation |
| Composition locator | [`backapp/cam_locator.py`](../backapp/cam_locator.py) | **unchanged**; preview JPEG mark only |
| Bayer offload pattern | [`backapp/cam_storage.py`](../backapp/cam_storage.py) | model for camera→other-process pixel handoff |
| Guide worker (new) | `backapp/guideControl.py` | isolation + geom + PI + crop JPEG + trims |
| Hub | [`backapp/rootserver.py`](../backapp/rootserver.py) | lock / sample / info / trim fan-out |
| Preview click | [`webapp/wasp/src/components/imgDisplay.vue`](../webapp/wasp/src/components/imgDisplay.vue) | tracking overlay + optional work-crop |
| Capture UI | [`webapp/wasp/src/components/captureOptions.vue`](../webapp/wasp/src/components/captureOptions.vue) | keep existing locator; add tracking panel *or* sibling |
| Manual rates | [`webapp/wasp/src/components/stepperControl.vue`](../webapp/wasp/src/components/stepperControl.vue) | feedforward + guide enable |
| Settings contract | [`backapp/docs/camera-settings-contract.md`](../backapp/docs/camera-settings-contract.md) | `track_*` + `guide_*` output fields |
| Sensor / exclusive access | [`backapp/docs/pi-hq-camera.md`](../backapp/docs/pi-hq-camera.md) | why the camera worker only *copies* the ROI |
| Camera bench pattern | [`backapp/scripts/run_cam_settings_bench.ps1`](../backapp/scripts/run_cam_settings_bench.ps1) | model for push-to-Pi guide benches |
| Guide benches (new, from phase B) | `test_guide_*_bench.py`, `scripts/run_guide_bench.ps1`, `docs/guide-bench-report.md` | Pi is the timing authority |
| Pico timing | [`firm/pico2w/README.md`](../firm/pico2w/README.md) | 100 ms rate ramp; sparse setpoints |
| Pi units | [`README.md`](../README.md) | add `astroscop-guide` when implemented |

---

## 15. One-sentence summary

Keep the empirical sidereal rate as feedforward; lock with a **new tracking locator** (ASC+/DEC+, DEC, focal length); crop a **small native RGB** around that lock; isolate the star in a **dedicated guide worker**; convert pixel drift to **arcseconds then motor steps** with `cos δ`; add small ASC/DEC rate trims — DEC included because polar alignment is only close.

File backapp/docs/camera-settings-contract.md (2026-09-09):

# Camera settings contract (HQ / IMX477)

**Audience:** agents updating [`rootserver.py`](../rootserver.py) and the web UI so they pass parameters the camera worker already enforces.

**Status:** camera worker is the source of truth. Rootserver today is a mostly opaque relay; UI still speaks a legacy shape. Both should migrate to the **canonical wire format** below.

---

## Source of truth (code)

| File | Role |
|---|---|
| [`cam_settings.py`](../cam_settings.py) | Pydantic `CameraSettings`, field classes (slow/fast/output), forbidden keys, `from_legacy_dict`, `diff_settings` |
| [`cam_spectrum.py`](../cam_spectrum.py) | `SpectrumStats` + `compute_rgb_spectrum` (display RGB) |
| [`cam_picamera2.py`](../cam_picamera2.py) | Worker: ingest → apply fast/slow → capture → WS emit (`srcimage`, `camTiming`) |
| [`cam_storage.py`](../cam_storage.py) | Bayer science storage **process** (shm ring → `*_bayer.npy` + meta) |
| [`test_cam_storage.py`](../test_cam_storage.py) | Camera-free storage / handoff tests |
| [`test_cam_settings_bench.py`](../test_cam_settings_bench.py) | On-device contract tests (must stay PASS) |
| [`pi-hq-camera.md`](pi-hq-camera.md) | Hardware, modes, ops / safe testing |
| [`hq-camera-capability-report.md`](hq-camera-capability-report.md) | Verified limits on `piscope` |
| [`cam-settings-bench-report.md`](cam-settings-bench-report.md) | Latest settings/spectrum/reconfig bench |

Do **not** invent overlapping gain controls. If code and this doc disagree, trust **`cam_settings.py`**.

---

## End-to-end data path

```text
UI  --msgtype:"params"-->  rootserver  --same msg-->  cam_picamera2
                                 │
                                 └──same msg-->  guideControl  (/guide)
                                                         │
                                                         ├─ geometry + PI
                                                         └─ guideInfo (sanitized) → UI
                                                            ctlparams GUIDE_D* → motor
```

- Camera WS path: `ws://…:8765/camera` (worker connects here).
- Guide WS path: `ws://…:8765/guide` (not a browser user). Same validated `params` as the camera; the camera only uses `track_*` for the RGB crop.
- Browser clients use the default user path; they send `params` and receive broadcast images / `camTiming` / sanitized `guideInfo`.
- Pixel tiles stay on shm (`astroscop-guide-tile`). Hub strips `tile` / `imageData` / `rgb`; a string `jpeg` on `guideInfo` is forwarded when `guide_show_crop` is on.
- Camera worker never applies settings on the WS receive thread: it queues `pending_settings`; the capture loop applies them between frames.

---

## WebSocket messages the camera understands

### Inbound to camera (from rootserver)

```json
{ "msgtype": "params", "data": { /* CameraSettings wire object — see below */ } }
```

Also:

```json
{ "msgtype": "serverOverwhelmed", "data": true }
```

When overwhelmed is true, the worker still acquires but **skips** WS JPEG emit.

Invalid `data` is logged and **ignored** (previous settings stay live). Validation errors must not crash the worker.

### Outbound from camera

**`srcimage`** (preview frame, rate-limited):

```json
{
  "msgtype": "srcimage",
  "imageData": "<base64 JPEG of display-sized RGB>",
  "usedParams": { /* see usedParams */ },
  "spectrum": { /* SpectrumStats — optional if compute fails */ }
}
```

**`camTiming`** (≈ every 3 s):

```json
{
  "msgtype": "camTiming",
  "data": {
    "imgbuffcount": 0,
    "science_published": 40,
    "science_dropped": 0,
    "science_written": 38,
    "science_errors": 0,
    "science_pending": 2,
    "science_slots": 199,
    "save_enabled": true,
    "save_root": "./savedimgs",
    "emitted": 12,
    "skipped": 40,
    "max_emit_fps": 8.0,
    "capture_fps": 11.2,
    "frame_time_ms": 89.3,
    "science_publish_fps": 11.2,
    "science_write_fps": 10.5,
    "emit_fps": 4.0,
    "queue_fill_eta_s": 281.4
  }
}
```

Rate fields are computed over the last timing window:

- `capture_fps` / `frame_time_ms` — wall-clock capture loop (independent of preview latency).
- `science_publish_fps` / `science_write_fps` — science ring enqueue / disk write rates.
- `emit_fps` — preview WS emits in the window (`emitted / Δt`).
- `queue_fill_eta_s` — net fill ETA: `(slots − pending) / max(0, publish − write)`; `null` when save is off or the queue is not filling.

Emit policy: **≤ `max_emit_fps` (default 8)**. Extra frames are skipped so acquisition keeps CPU. UI/rootserver must not assume every captured frame is sent.

Steady-state acquisition priority:

- Capture runs in a dedicated thread pool; preview JPEG/spectrum packing runs in a separate emit pool (not on the asyncio loop).
- Bayer science frames (when `save_enabled`) are published into a **single contiguous shared_memory slab** (ring of slots) and written by a **separate OS process** ([`cam_storage.py`](../cam_storage.py)) — never RGB/JPEG to disk. Ring size ≈ 60% RAM / frame (also capped by `/dev/shm`).
- Preview uses a depth-1 buffer; science publish does **not** go through that buffer.
- Slow reconfigure (sensor mode / `include_raw`) may briefly block; output fields (`save_*`, display, emit FPS) do not.

---

## Canonical wire format (`CameraSettings`)

Preferred `params.data` shape. Extra keys are **ignored** (`extra="ignore"`). Types and bounds are enforced by Pydantic.

### Fields

| Field | Type | Default | Class | Notes |
|---|---|---|---|---|
| `sensor_preset` | `"full"` \| `"full_2160"` \| `"bin2x2"` \| `"bin2x2_1080"` \| `"bin2x2_crop"` | `"bin2x2"` | **slow** | Native IMX477 modes only |
| `main_width` | int ≥ 2 or null | `null` | **slow** | Must pair with `main_height`; if both null → preset size |
| `main_height` | int ≥ 2 or null | `null` | **slow** | |
| `include_raw` | bool | `true` | **slow** | Configure raw Bayer stream |
| `shutter_us` | int 1…600_000_000 | `150000` | **fast** | Exposure microseconds |
| `analog_gain` | float (0, 64] | `1.0` | **fast** | **Only** gain control |
| `colour_gain_r` | float (0, 32] | `3.5` | **fast** | AWB always off |
| `colour_gain_b` | float (0, 32] | `1.5` | **fast** | |
| `scaler_crop` | `[x,y,w,h]` or null | `null` | **fast** | Sensor coords; w/h forced even |
| `science_neutral` | bool | `true` | **fast** | Worker path is always manual / neutral tone |
| `preview_div` | `1` \| `2` \| `4` \| `8` | `2` | **output** | JPEG downsample vs capture RGB (full / ½ / ¼ / ⅛); aspect preserved |
| `save_enabled` | bool | `false` | **output** | Runtime arm/disarm Bayer disk persistence |
| `save_root` | string | `"./savedimgs"` | **output** | Runtime destination root (SD, `/dev/shm`, USB, …) |
| `save_format` | string | `"none"` | **output** | Legacy: `"none"` / `"npy"` map to `save_enabled`; science writes Bayer `.npy` only |
| `save_section` | string | `"test"` | **output** | |
| `save_subsection` | string | `""` | **output** | |
| `max_emit_fps` | float (0, 60] | `8.0` | **output** | Preview emit cap |
| `locator_enabled` | bool | `false` | **output** | Burn tracking mark into preview JPEG only |
| `locator_x` | float 0…1 | `0.5` | **output** | Full IMX477 sensor X (0 = left) |
| `locator_y` | float 0…1 | `0.5` | **output** | Full IMX477 sensor Y (0 = top) |
| `locator_size` | float 0.15…3.0 | `1.0` | **output** | Circle radius scale vs the default mark |
| `track_enabled` | bool | `false` | **output** | Copy a native RGB tile for the guide worker (not isolation / not JPEG) |
| `track_x` | float 0…1 | `0.5` | **output** | Full IMX477 lock X (same space as `locator_x`) |
| `track_y` | float 0…1 | `0.5` | **output** | Full IMX477 lock Y |
| `track_roi` | int 8…64 | `32` | **output** | Crop **half-size** in capture pixels (64×64 default) |
| `track_theta_deg` | float | `0` | **output** | Chip rotation: θ=0 means ASC+ is +u, DEC+ is +v |
| `track_flip_asc` | bool | `false` | **output** | Flip ASC axis after rotation |
| `track_flip_dec` | bool | `false` | **output** | Flip DEC axis after rotation |
| `guide_dec_deg` | float −90…90 | `0` | **output** | Celestial δ for `cos δ` (typed; not mount counts) |
| `guide_focal_mm` | float ≥ 0 | `18` | **output** | OTA focal length; `≤ 0` refuses the guide loop |
| `guide_show_crop` | bool | `false` | **output** | Guide worker encodes a small tile JPEG; hub forwards `guideInfo.data.jpeg` (still strips `tile`) |
| `guide_stack_n` | int 1…15 | `5` | **output** | Median-stack length in the guide worker before isolate |
| `guide_kp` | float 0…4 | `0.80` | **output** | PI proportional gain (STEP/s per axis pixel); live, does not reset I |
| `guide_ki` | float 0…0.5 | `0.008` | **output** | PI integral gain (STEP/s per axis pixel per s); live, does not reset I |
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

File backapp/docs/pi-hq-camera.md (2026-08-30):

# Raspberry Pi HQ Camera (IMX477)

Static reference for the HQ camera used by astroScop on host **`piscope`**.

**Implementing rootserver or UI parameter plumbing?** Use the contract first:

→ **[`camera-settings-contract.md`](camera-settings-contract.md)** — canonical wire format, slow/fast/output fields, forbidden keys, WS messages.

Docs index: [`README.md`](README.md)
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

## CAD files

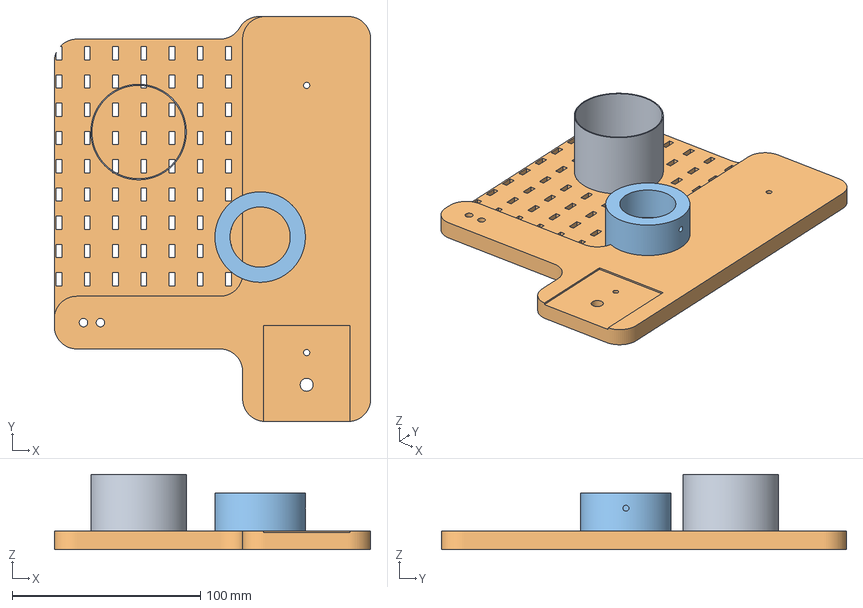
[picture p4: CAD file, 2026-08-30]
3dmodels/barlow_adaptor/barlow_adaptor.3mf
168.0 x 215.0 x 40.0 mm
barlow_adaptor.stl
marks_holder.stl
m42_to_1_25.stl

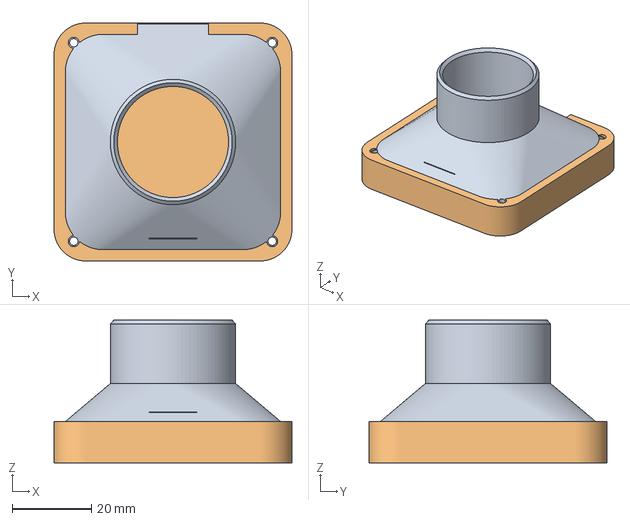
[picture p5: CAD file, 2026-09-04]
3dmodels/hq_camera_holder/hq_camera_holder_1_25_body.3mf
60.0 x 60.0 x 36.0 mm
hq_camera_holder_1_25_body.stl
hq_camera_holder_1_25_cover.stl

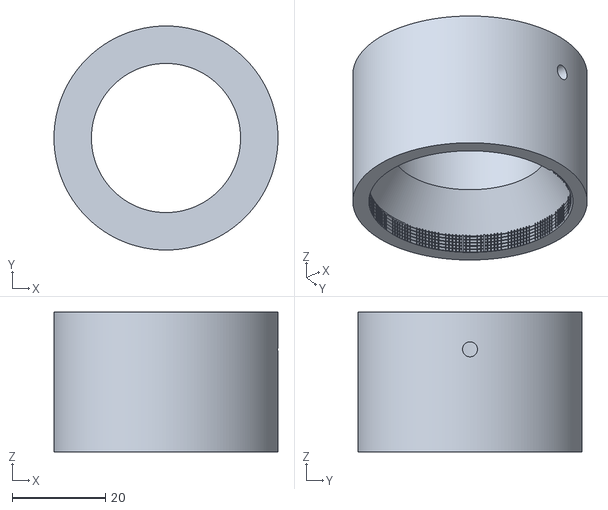
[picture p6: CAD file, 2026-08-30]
3dmodels/m42_to_1_25/m42_to_1_25.stl
48.0 x 48.0 x 30.0

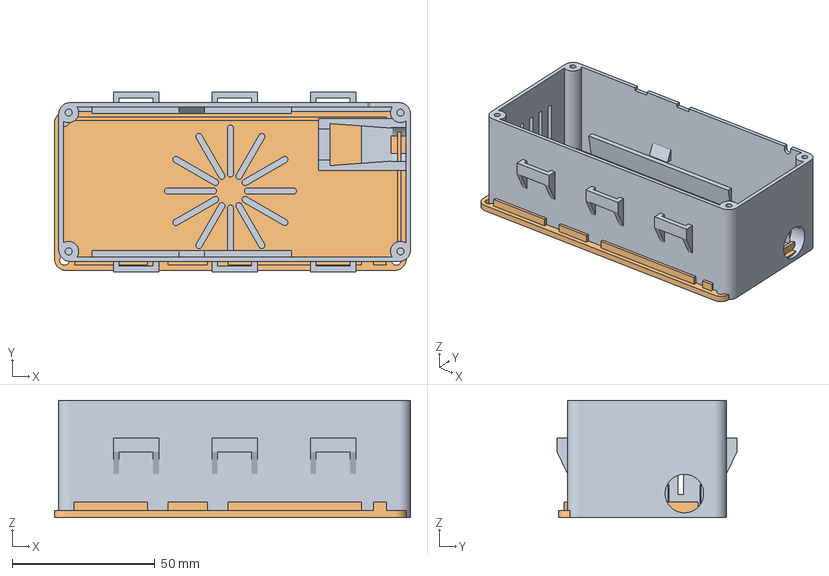
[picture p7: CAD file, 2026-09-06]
3dmodels/motor_board_box/cover.3mf
124.7 x 63.0 x 41.0 mm
motor_board_box.stl
cover.stl

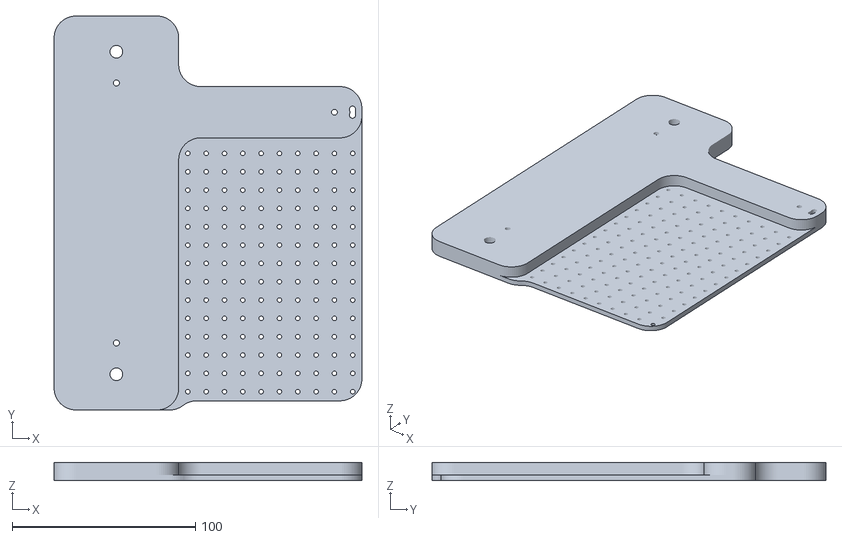
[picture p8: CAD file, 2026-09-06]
3dmodels/scope_t_plate/scope_t_plate.stl
168.0 x 215.0 x 10.0

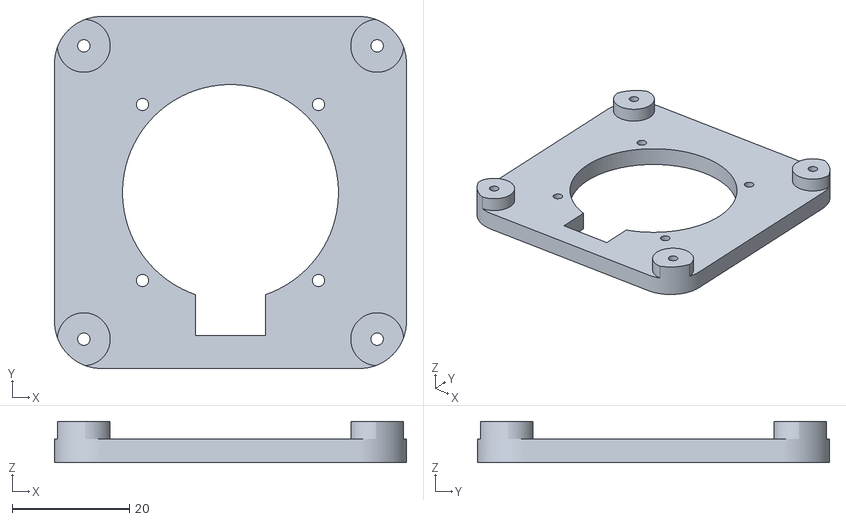
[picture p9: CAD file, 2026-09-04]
3dmodels/hq_camera_holder/body_open.stl
60.0 x 60.0 x 7.00

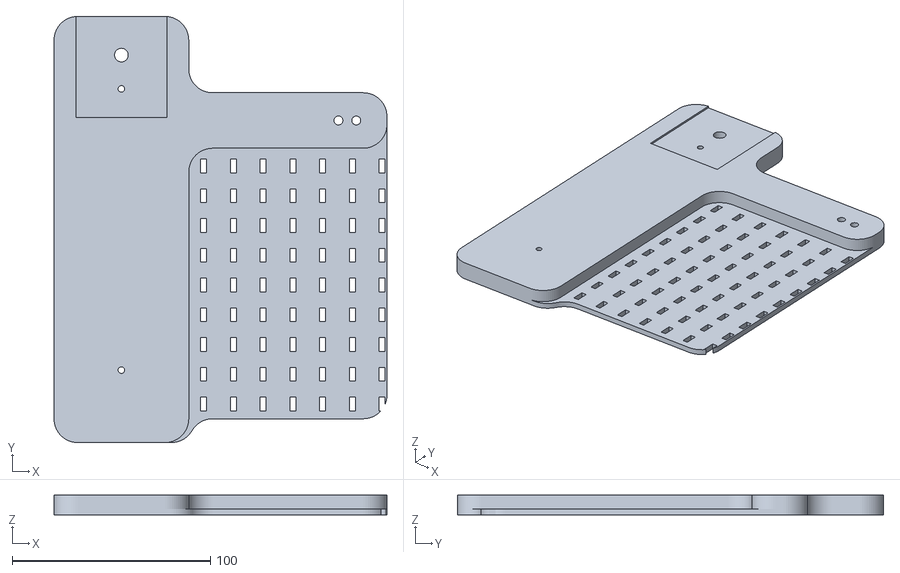
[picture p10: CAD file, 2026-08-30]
3dmodels/marks_holder/marks_holder.stl
168.0 x 215.0 x 10.0

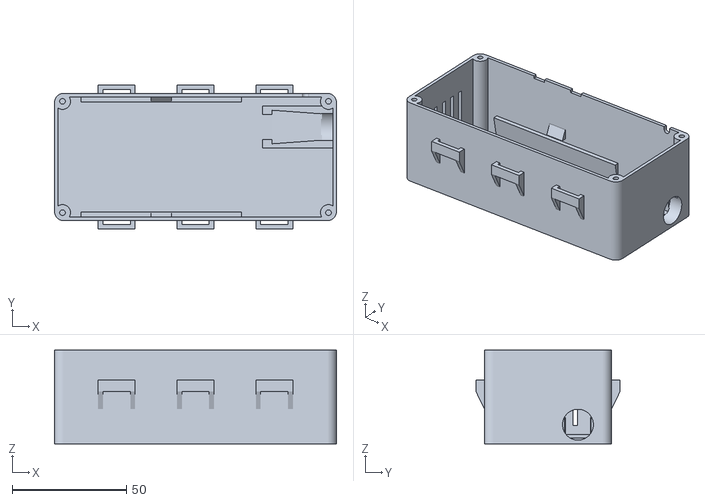
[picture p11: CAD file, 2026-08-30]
3dmodels/motor_board_box/motor_board_box.stl
123.2 x 63.0 x 41.0

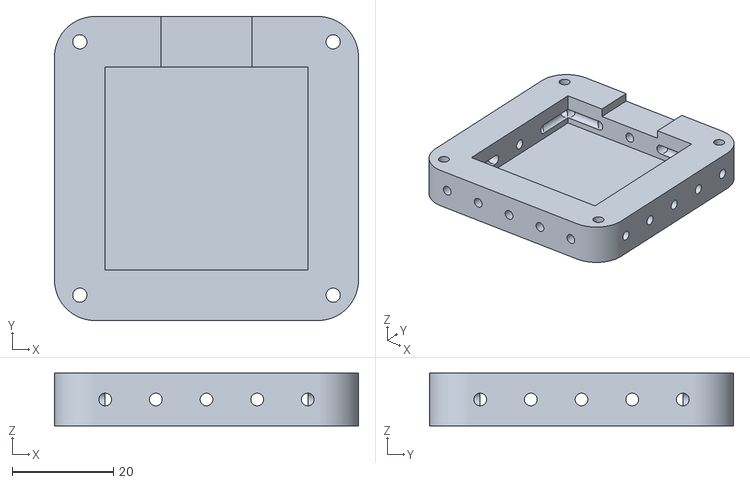
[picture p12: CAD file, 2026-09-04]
3dmodels/hq_camera_holder/hq_camera_holder_1_25_cover.stl
60.0 x 60.0 x 10.4

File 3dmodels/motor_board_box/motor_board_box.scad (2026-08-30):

// Motor board enclosure
// Two printable parts: a board-holding bottom box and a screw-fastened cover.
// All dimensions are in millimetres and intentionally live in this file.
// The 12V adapter shape lives in barrel_adapter.scad (`use` imports modules only).
use <barrel_adapter.scad>

/* [Output] */
part = "assembly"; // [bottom, cover, assembly]
show_board_preview = true;
show_adapter_preview = true;

/* [Feature switches] */
board_grooves_enable = true;
flat_wire_notches_enable = true;
usb_notch_enable = true;
adapter_pocket_enable = true;
adapter_holder_enable = true;
strap_loops_enable = true;
screw_mounts_enable = true;
cover_lip_enable = true;
cover_vents_enable = true;
xminus_vents_enable = true;

/* [Board and clearances] */
board_length = 70.0;
board_width = 50.0;
board_thickness = 1.6;
clearance_below_board = 10.0;
clearance_above_board = 27.0;
board_end_margin_x_minus = 10.0;
board_end_margin_x_plus = 40.0;
board_side_gap = 1.2;
board_vertical_fit = 0.25;

/* [Box] */
wall_thickness = 1.6;
floor_thickness = 2.4;
box_corner_radius = 4.0;

/* [Board edge grooves] */
groove_support_depth = 1.0;
groove_tab_depth = 1.0;
groove_tab_height = 5.0;
groove_tab_length = 9.0;
groove_tab_positions = [0.50]; // fractions along board length

/* [Cover] */
cover_thickness = 2.4;
cover_lip_depth = 3.0;
cover_lip_thickness = 1.2;
cover_fit_clearance = 0.25;
cover_lip_wire_clearance = 0.6;

/* [Cover airflow rays] */
cover_vent_count = 12;
cover_vent_width = 2.2;
cover_vent_inner_radius = 6.0;
cover_vent_outer_margin = 3.0;

/* [M3 cover screws] */
m3_clearance_diameter = 3.4;
m3_tap_diameter = 2.5;
screw_post_diameter = 7.0;
screw_post_edge_offset = screw_post_diameter / 2;
screw_tap_depth = 20.0;

/* [Flat wire notches] */
flat_notch_width = 6.0;
flat_notch_depth = 1.3;
flat_notch_board_fractions = [0.35, 0.65];

/* [USB wire notch] */
usb_notch_diameter = 3.0;
usb_notch_from_x_plus = 12.0;

/* [12V adapter placement] */
// Reference plane: inside face of the X+ end wall. The barrel extends outward.
adapter_from_y_plus = 6.0;
adapter_x_shift = -5.0;
adapter_floor_lift = 0.0;
adapter_fit_clearance = 0.25;

/* [12V adapter holder] */
adapter_holder_side_margin = 2.0;
adapter_holder_end_margin = -2.0;
adapter_holder_height_fraction = 0.70;

/* [Strap loops] */
strap_width = 12.0;
strap_thickness = 1.2;
strap_fit_clearance = 0.5;
strap_loop_x_fractions = [0.22, 0.50, 0.78];
strap_loop_side_width = 2.0;
strap_loop_bridge_thickness = 2.0;
strap_loop_bridge_height = 5.0;
strap_loop_z_fraction = 0.62;
strap_loop_ramp_extra = 4.0;

/* [X- wall vents] */
xminus_vent_count = 5;
xminus_vent_width = 2.0;
xminus_vent_height = 20.0;
xminus_vent_bottom_z = 8.0;
xminus_vent_y_margin = 10.0;

/* [Quality] */
$fn = $preview ? 32 : 96;

epsilon = 0.05;

inner_length =
    board_end_margin_x_minus + board_length + board_end_margin_x_plus;
inner_width = board_width + 2 * board_side_gap;
inner_height = clearance_below_board + board_thickness + clearance_above_board;

box_length = inner_length + 2 * wall_thickness;
box_width = inner_width + 2 * wall_thickness;
box_height = floor_thickness + inner_height;

board_x = wall_thickness + board_end_margin_x_minus;
board_y = wall_thickness + board_side_gap;
board_bottom_z = floor_thickness + clearance_below_board;
board_top_z = board_bottom_z + board_thickness;

adapter_wall_x = box_length - wall_thickness + adapter_x_shift;
adapter_center_y =
    box_width - wall_thickness -
    adapter_from_y_plus -
    adapter_pyramid_inner_width() / 2;
adapter_center_z =
    floor_thickness +
    adapter_floor_lift +
    adapter_pyramid_inner_height() / 2;
adapter_inner_end_x =
    adapter_wall_x -
    (
        adapter_pyramid_length() -
        adapter_terminal_overlap() +
        adapter_terminal_length() +
        adapter_fit_clearance
    );
adapter_body_height =
    adapter_pyramid_inner_height() + adapter_terminal_z_offset();
adapter_holder_top_z =
    floor_thickness +
    adapter_floor_lift +
    adapter_holder_height_fraction * adapter_body_height;

assert(
    board_length > 0 && board_width > 0 && board_thickness > 0,
    "Board dimensions must be positive"
);
assert(
    clearance_below_board > 0,
    "Bottom clearance must be positive"
);
assert(
    clearance_above_board > cover_lip_depth,
    "Top clearance must exceed the cover lip depth"
);
assert(
    wall_thickness > 0 && floor_thickness > 0,
    "Wall and floor thicknesses must be positive"
);
assert(
    box_corner_radius >= wall_thickness &&
    2 * box_corner_radius < min(box_length, box_width),
    "Box corner radius is invalid"
);
assert(
    groove_support_depth > 0 && groove_support_depth <= board_width / 2,
    "Board groove support depth is invalid"
);
assert(
    groove_tab_depth > 0 &&
    groove_tab_height > 0 &&
    groove_tab_length > 0,
    "Board retaining-tab dimensions must be positive"
);
assert(
    cover_fit_clearance >= 0 &&
    cover_lip_thickness > 0 &&
    cover_lip_depth > 0,
    "Cover lip dimensions are invalid"
);
assert(
    cover_vent_count == floor(cover_vent_count) &&
    cover_vent_count >= 2 &&
    cover_vent_width > 0 &&
    cover_vent_inner_radius >= 0 &&
    cover_vent_outer_margin >= 0,
    "Cover vent parameters are invalid"
);
assert(
    m3_tap_diameter < screw_post_diameter - 2,
    "M3 tapping hole leaves too little material in the post"
);
assert(
    screw_tap_depth > 0 && screw_tap_depth < box_height - floor_thickness,
    "Screw tap depth must remain above the box floor"
);
assert(
    board_x > screw_post_edge_offset + screw_post_diameter / 2,
    "Increase board_end_margin_x_minus to clear the X- screw posts"
);
assert(
    board_x + board_length <
        box_length - screw_post_edge_offset - screw_post_diameter / 2,
    "Increase board_end_margin_x_plus to clear the X+ screw posts"
);
assert(
    adapter_center_y - adapter_pyramid_inner_width() / 2 > wall_thickness &&
    adapter_center_y + adapter_pyramid_inner_width() / 2 <
        box_width - wall_thickness,
    "12V adapter does not fit along the X+ wall"
);
assert(
    adapter_center_z - adapter_pyramid_inner_height() / 2 >= floor_thickness &&
    adapter_holder_height_fraction > 0 &&
    adapter_holder_height_fraction < 1 &&
    adapter_holder_top_z < box_height,
    "12V adapter does not fit vertically in the box"
);
assert(
    adapter_terminal_overlap() >= 0 &&
    adapter_terminal_overlap() < adapter_terminal_length(),
    "12V terminal overlap must be smaller than its length"
);
assert(
    adapter_inner_end_x > board_x + board_length,
    "Increase board_end_margin_x_plus to clear the 12V adapter body"
);
assert(
    usb_notch_from_x_plus > usb_notch_diameter / 2 &&
    usb_notch_from_x_plus <
        board_end_margin_x_plus - usb_notch_diameter / 2,
    "USB notch must remain inside the X+ clearance area"
);

strap_loop_protrusion =
    strap_thickness + strap_fit_clearance + strap_loop_bridge_thickness;
strap_loop_total_width = strap_width + 2 * strap_loop_side_width;
strap_loop_z0 =
    box_height * strap_loop_z_fraction - strap_loop_bridge_height / 2;
strap_loop_ramp_z =
    strap_loop_z0 - strap_loop_protrusion - strap_loop_ramp_extra;

assert(
    strap_loop_z0 > 0 &&
    strap_loop_z0 + strap_loop_bridge_height < box_height,
    "Strap loops must stay within the box height"
);
assert(
    strap_loop_ramp_z > 0,
    "Strap loop ramps would go below the box floor"
);

for (position = strap_loop_x_fractions) {
    strap_center_x = box_length * position;

    assert(
        position > 0 && position < 1 &&
        strap_center_x - strap_loop_total_width / 2 > 0 &&
        strap_center_x + strap_loop_total_width / 2 < box_length,
        "A strap loop lies outside the long wall"
    );
}

assert(
    xminus_vent_count == floor(xminus_vent_count) &&
    xminus_vent_count >= 1 &&
    xminus_vent_width > 0 &&
    xminus_vent_height > 0 &&
    xminus_vent_bottom_z > 0 &&
    xminus_vent_bottom_z + xminus_vent_height < box_height &&
    xminus_vent_y_margin > 0 &&
    2 * xminus_vent_y_margin + xminus_vent_count * xminus_vent_width <
        box_width,
    "X- wall vents do not fit"
);

module rounded_rect_prism(length, width, height, radius) {
    assert(radius > 0, "Rounded rectangle radius must be positive");
    hull() {
        for (x = [radius, length - radius])
            for (y = [radius, width - radius])
                translate([x, y, 0])
                    cylinder(h = height, r = radius);
    }
}

module empty_box_shell() {
    inner_radius = max(epsilon, box_corner_radius - wall_thickness);

    difference() {
        rounded_rect_prism(
            box_length,
            box_width,
            box_height,
            box_corner_radius
        );

        translate([wall_thickness, wall_thickness, floor_thickness])
            rounded_rect_prism(
                inner_length,
                inner_width,
                inner_height + epsilon,
                inner_radius
            );
    }
}
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

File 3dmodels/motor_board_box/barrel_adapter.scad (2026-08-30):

// Isolated 12V barrel-to-screw-terminal adapter
// Outside -> inside along +Y. The wall interface is the Y=0 plane.
// Negative Y is the barrel (outside the box). Positive Y is inside the box.
// All dimensions are in millimetres and live in this file.

/* [Adapter preview] */
adapter_show_sections = true;

/* [Barrel — outside] */
adapter_barrel_diameter = 13.0;
adapter_barrel_length = 9.0;

/* [Truncated pyramid — body] */
// Face against the barrel / wall (outside)
adapter_pyramid_outer_width = 11.0;
adapter_pyramid_outer_height = 11.0;
// Face toward the screw terminal (inside)
adapter_pyramid_inner_width = 14.2;
adapter_pyramid_inner_height = 12.0;
adapter_pyramid_length = 21.4;

/* [Screw terminal — inside] */
// Longer side is aligned with the pyramid inner-face width.
adapter_terminal_width = 10.3;
adapter_terminal_height = 10.1;
adapter_terminal_length = 8.0;
// How far the terminal sits back into the pyramid inner face.
adapter_terminal_overlap = 2.0;
// Shift the terminal along +Z (up) from the pyramid centreline.
adapter_terminal_z_offset = 1.0;

/* [Quality] */
adapter_fn = $preview ? 32 : 96;

function adapter_pyramid_inner_width() = adapter_pyramid_inner_width;
function adapter_pyramid_inner_height() = adapter_pyramid_inner_height;
function adapter_pyramid_length() = adapter_pyramid_length;
function adapter_terminal_overlap() = adapter_terminal_overlap;
function adapter_terminal_length() = adapter_terminal_length;
function adapter_terminal_z_offset() = adapter_terminal_z_offset;

module rectangular_frustum_y(length, outer_width, outer_height, inner_width, inner_height) {
    polyhedron(
        points = [
            [-outer_width / 2, 0, -outer_height / 2],
            [ outer_width / 2, 0, -outer_height / 2],
            [ outer_width / 2, 0,  outer_height / 2],
            [-outer_width / 2, 0,  outer_height / 2],
            [-inner_width / 2, length, -inner_height / 2],
            [ inner_width / 2, length, -inner_height / 2],
            [ inner_width / 2, length,  inner_height / 2],
            [-inner_width / 2, length,  inner_height / 2]
        ],
        faces = [
            [0, 3, 2, 1],
            [4, 5, 6, 7],
            [0, 1, 5, 4],
            [1, 2, 6, 5],
            [2, 3, 7, 6],
            [3, 0, 4, 7]
        ],
        convexity = 4
    );
}

module adapter_barrel(clearance = 0) {
    translate([0, -adapter_barrel_length - clearance, 0])
        rotate([-90, 0, 0])
            cylinder(
                h = adapter_barrel_length + 2 * clearance,
                d = adapter_barrel_diameter + 2 * clearance,
                $fn = adapter_fn
            );
}

module adapter_pyramid(clearance = 0) {
    translate([0, -clearance, 0])
        rectangular_frustum_y(
            adapter_pyramid_length + 2 * clearance,
            adapter_pyramid_outer_width + 2 * clearance,
            adapter_pyramid_outer_height + 2 * clearance,
            adapter_pyramid_inner_width + 2 * clearance,
            adapter_pyramid_inner_height + 2 * clearance
        );
}

module adapter_terminal(clearance = 0) {
    translate([
        -adapter_terminal_width / 2 - clearance,
        adapter_pyramid_length - adapter_terminal_overlap,
        -adapter_terminal_height / 2 - clearance + adapter_terminal_z_offset
    ])
        cube([
            adapter_terminal_width + 2 * clearance,
            adapter_terminal_length + 2 * clearance,
            adapter_terminal_height + 2 * clearance
        ]);
}

// Full physical adapter. clearance grows every face for use as a box cutter.
module adapter_component(clearance = 0) {
    if (adapter_show_sections && clearance == 0) {
        color("Silver")
            adapter_barrel();
        color("DimGray")
            adapter_pyramid();
        color("ForestGreen")
            adapter_terminal();
    } else {
        union() {
            adapter_barrel(clearance);
            adapter_pyramid(clearance);
            adapter_terminal(clearance);
        }
    }
}

adapter_component();

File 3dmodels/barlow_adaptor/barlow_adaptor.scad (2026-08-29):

// Barlow length adaptor ring
// Outer: 2" telescope focuser/mount barrel
// Inner: 46 mm bore
// Height: 40 mm

/* [Dimensions] */
outer_diameter = 50.8; // 2" standard eyepiece barrel (ISO 14134)
inner_diameter = 49.4;
height = 40.0;

/* [Fit / print] */
// Reduce OD slightly so a printed part slides into a metal 2" focuser
outer_clearance = 0.1;
// Extra ID for print shrinkage / easy fit of the inner piece
inner_clearance = 0.1;

/* [Quality] */
$fn = 200;

od = outer_diameter - outer_clearance;
id = inner_diameter + inner_clearance;

assert(od > id, "Outer diameter must be larger than inner diameter");

difference() {
    cylinder(h = height, d = od, center = false);
    translate([0, 0, -0.1])
        cylinder(h = height + 0.2, d = id, center = false);
}

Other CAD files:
3dmodels/marks_holder/maks_holder.3mf
3dmodels/hq_camera_holder/cover.stl
3dmodels/hq_camera_holder/body_1_25.scad
3dmodels/barlow_adaptor/barlow_adaptor.stl
3dmodels/hq_camera_holder/body_2.scad
3dmodels/hq_camera_holder/body_open.scad
3dmodels/hq_camera_holder/cover.scad
3dmodels/hq_camera_holder/hq_camera_holder_1_25_body.stl
3dmodels/hq_camera_holder/hq_camera_holder_lib.scad
3dmodels/m42_to_1_25/m42_to_1_25.scad
3dmodels/marks_holder/marks_holder.scad
3dmodels/motor_board_box/cover.stl
3dmodels/scope_t_plate/scope_t_plate.scad

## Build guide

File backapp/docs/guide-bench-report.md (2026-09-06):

# Guide loop — bench report

Generated: **2026-09-05 15:46:54 UTC**  
This pull: [`guide_worker_20260905T174603`](../cam_test_out/guide_worker_20260905T174603)  
Merged latest: [`guide-bench-latest`](guide-bench-latest)  
Host: **piscope** (`aarch64`)  
Overall: **PASS**

Pi is the timing authority (evolution §10). A section without `host=piscope` / `aarch64` is not a phase gate.

## Phase B — `guide_geom` (`pixels_to_axis_steps`)

- host: **piscope** (`aarch64`)
- iters: **10000**
- tile_size: n/a (scalar math)
- p50: **11.95 µs**
- p95: **12.22 µs**
- max: **37.59 µs**
- gate: p95 **< 0.5 ms** → **PASS**
- Pi host check: **PASS**

Raw: [`geom_bench.json`](guide-bench-latest/geom_bench.json)

## Phase C — `guide_isolate` (`isolate_star`)

- host: **piscope** (`aarch64`)
- Pi host check: **PASS**

| tile | SNR | iters | p50 | p95 | max | gate | result |
|---|-----|---|-----|-----|-----|---|---|
| 64² | high | 400 | 0.724 ms | 0.809 ms | 1.112 ms | < 5.0 ms | **PASS** |
| 64² | mid | 400 | 0.744 ms | 0.824 ms | 1.171 ms | < 5.0 ms | **PASS** |
| 64² | low | 400 | 0.737 ms | 0.815 ms | 0.934 ms | < 5.0 ms | **PASS** |
| 128² | high | 200 | 1.510 ms | 3.129 ms | 3.410 ms | < 15.0 ms | **PASS** |
| 128² | mid | 200 | 1.486 ms | 1.575 ms | 1.792 ms | < 15.0 ms | **PASS** |
| 128² | low | 200 | 1.487 ms | 1.573 ms | 1.667 ms | < 15.0 ms | **PASS** |

Timing: **PASS**. Raw: [`isolate_bench.json`](guide-bench-latest/isolate_bench.json)

## Phase D — `guide_handoff` (live RGB crop vs off)

- host: **piscope** (`aarch64`)
- Pi host check: **PASS**
- timing: **PASS**

- **crop off**: frame_time **59.29 ms**, emit_fps **2.437**
- **crop on 64²**: frame_time **58.84 ms**, emit_fps **2.514**, extract p95 **0.377 ms**, handoff p95 **0.444 ms**
- **crop on 128²**: frame_time **60.90 ms**, emit_fps **2.517**, extract p95 **0.501 ms**, handoff p95 **0.584 ms**

Raw: [`crop_bench.json`](guide-bench-latest/crop_bench.json)

## Phase E — `guideControl` (synthetic tile → PI)

- host: **piscope** (`aarch64`)
- Pi host check: **PASS**
- timing: **PASS**

| case | p50 | p95 | max | gen | proc | backlog | result |
|---|-----|-----|-----|-----|---|---|---|
| hz5_jpeg_off | 1.549 ms | 4.703 ms | 56.622 ms | 150 | 150 | 0 | **PASS** |
| hz10_jpeg_off | 1.533 ms | 3.884 ms | 6.539 ms | 100 | 100 | 0 | **PASS** |
| hz5_jpeg_on | 2.082 ms | 6.142 ms | 26.079 ms | 40 | 40 | 0 | **PASS** |

Raw: [`worker_bench.json`](guide-bench-latest/worker_bench.json)

Later phases append worker sections here.

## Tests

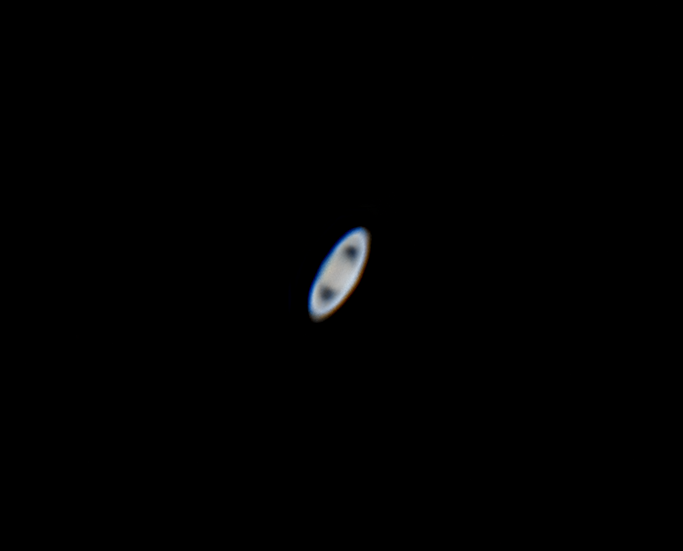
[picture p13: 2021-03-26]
backapp/testimgs/sat1.png

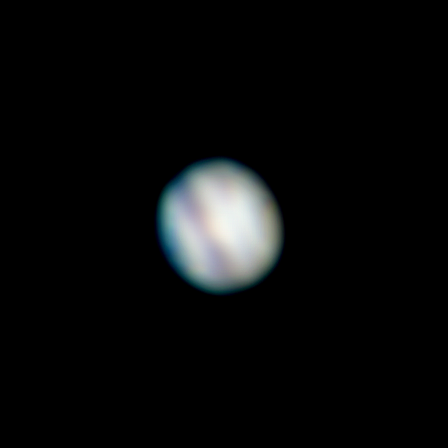
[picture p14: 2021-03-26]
backapp/testimgs/jup1.png

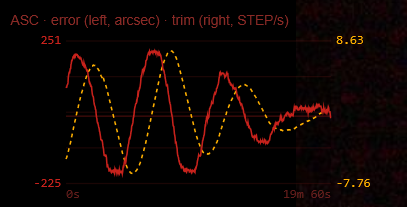
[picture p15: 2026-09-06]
backapp/testimgs/tuning.png

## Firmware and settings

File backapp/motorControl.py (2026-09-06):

"""ASC + DEC motor worker: UI ctlparams → Pico 2 W USB serial → motorInfo telemetry.

Replaces the legacy Arduino binary-protocol worker. Connects to rootserver at
ws://localhost:8765/motor and drives firm/pico2w/main.py over USB CDC.
"""

from __future__ import annotations

import argparse
import asyncio
import logging
import time
from typing import Optional

from jobutils import Jobstate, clientConnection, formatstr, infiniteRetry
from pico_motor import (
    PicoMotorClient,
    PicoNotFoundError,
    resolve_pico_port_required,
)
from asc_rates import (
    ASC_STEPS_PER_DEGREE,
    sidereal_speed_cmd,
)
from guide_mixer import RateMixer, needs_write
from ws_messages import (
    CTL_ASC,
    CTL_ASC_CURR,
    CTL_ASC_RESET,
    CTL_ASC_SIDEREAL,
    CTL_ASC_ZERO,
    CTL_DEC,
    CTL_DEC_CURR,
    CTL_DEC_RESET,
    CTL_DEC_ZERO,
    CTL_GUIDE_DASC,
    CTL_GUIDE_DDEC,
    CTL_GUIDE_DISABLE,
    CTL_GUIDE_ENABLE,
    CTL_MOTOR_ARM,
    CTL_MOTOR_DISARM,
)

# Open-loop degrees from empirical sidereal lock (see asc_rates.py).
DEFAULT_STEP_BY_DEGREE = ASC_STEPS_PER_DEGREE
TELEMETRY_PERIOD_S = 0.2
SEARCH_PERIOD_S = 0.5
PING_PERIOD_S = 5.0

log = logging.getLogger("motor")


class AxisTracker:
    """Open-loop position from commanded step rate for one axis."""

    def __init__(self, step_by_degree: float = DEFAULT_STEP_BY_DEGREE):
        self.step_by_degree = float(step_by_degree)
        self.absolute_step = 0.0
        self._last_t = time.monotonic()
        self.cmd_dir = 0
        self.cmd_step_us = 0
        self.enabled = False

    def set_command(self, dir_bit: int, step_us: int, enabled: bool) -> None:
        self.integrate()
        self.cmd_dir = int(dir_bit)
        self.cmd_step_us = int(step_us) if enabled else 0
        self.enabled = bool(enabled) and self.cmd_step_us > 0

    def stop(self) -> None:
        self.integrate()
        self.cmd_step_us = 0
        self.enabled = False

    def zero(self) -> None:
        self.integrate()
        self.absolute_step = 0.0

    def integrate(self) -> None:
        now = time.monotonic()
        dt = now - self._last_t
        self._last_t = now
        if not self.enabled or self.cmd_step_us <= 0 or dt <= 0:
            return
        rate = 1_000_000.0 / float(self.cmd_step_us)
        signed = rate if self.cmd_dir == 0 else -rate
        self.absolute_step += signed * dt


class MountTracker:
    def __init__(self, step_by_degree: float = DEFAULT_STEP_BY_DEGREE):
        self.asc = AxisTracker(step_by_degree)
        self.dec = AxisTracker(step_by_degree)

    def stop_all(self) -> None:
        self.asc.stop()
        self.dec.stop()

    def snapshot(self) -> dict:
        self.asc.integrate()
        self.dec.integrate()
        return {
            "ascStep": int(round(self.asc.absolute_step)),
            "decStep": int(round(self.dec.absolute_step)),
            "newascDeg": float(self.asc.absolute_step) / self.asc.step_by_degree,
            "newdecDeg": float(self.dec.absolute_step) / self.dec.step_by_degree,
            "ascDir": self.asc.cmd_dir,
            "ascStepUs": self.asc.cmd_step_us if self.asc.enabled else 0,
            "ascEn": 1 if self.asc.enabled else 0,
            "decDir": self.dec.cmd_dir,
            "decStepUs": self.dec.cmd_step_us if self.dec.enabled else 0,
            "decEn": 1 if self.dec.enabled else 0,
        }


# Shared across WS + serial loops
pico: Optional[PicoMotorClient] = None
tracker = MountTracker()
mixer = RateMixer()
ui_armed = False
link_error: Optional[str] = None
force_rescan: Optional[asyncio.Event] = None
serial_lock: Optional[asyncio.Lock] = None
_last_sent_asc: Optional[float] = None
_last_sent_dec: Optional[float] = None


def _request_rescan() -> None:
    if force_rescan is not None:
        force_rescan.set()


def motor_info_payload(*, link: Optional[str] = None) -> dict:
    """Build motorInfo including explicit Pico link status for the UI."""
    snap = tracker.snapshot()
    connected = pico is not None
    if link is None:
        if connected:
            link = "connected"
        elif link_error:
            link = "error"
        else:
            link = "searching"
    snap.update(
        {
            "connected": connected,
            "port": pico.port if pico is not None else None,
            "link": link,
            "error": link_error,
            "armed": ui_armed,
        }
    )
    snap.update(mixer.snapshot())
    return snap


async def emit_motor_info(state: Jobstate, *, link: Optional[str] = None) -> None:
    await state.send_msg("motorInfo", motor_info_payload(link=link))


async def _serial_call(fn, *args):
    """Run blocking Pico I/O under the shared lock (WS + telemetry share one port)."""
    if serial_lock is None:
        return await asyncio.to_thread(fn, *args)
    async with serial_lock:
        return await asyncio.to_thread(fn, *args)


def _open_pico_client(resolved: str) -> PicoMotorClient:
    """Blocking open + boot drain + ping/status (run in a thread)."""
    client = PicoMotorClient(resolved)
    try:
        for line in client.drain_boot():
            log.info("boot: %s", line)
        log.info("ping: %s", client.ping())
        log.info("status: %s", client.status())
        return client
    except Exception:
        try:
            client.close()
        except Exception:
            pass
        raise


async def _close_pico() -> None:
    global pico, link_error, _last_sent_asc, _last_sent_dec
    client = pico
    pico = None
    _last_sent_asc = None
    _last_sent_dec = None
    mixer.clear_trims()
    if client is None:
        return
    try:
        await _serial_call(client.close)
    except Exception:
        pass
    tracker.stop_all()
    log.info("Pico serial closed")


async def _apply_mixed_speeds(state: Jobstate, log_h) -> bool:
    """Write commanded = ff + trim to Pico for axes that changed. False on serial fail."""
    global link_error, _last_sent_asc, _last_sent_dec
    if pico is None:
        log_h.warning("speed apply ignored — Pico not open")
        await emit_motor_info(state)
        return False

    cmd_asc = mixer.commanded_asc()
    cmd_dec = mixer.commanded_dec()
    try:
        if needs_write(_last_sent_asc, cmd_asc):
            reply = await _serial_call(pico.set_speed_asc, cmd_asc)
            tracker.asc.set_command(pico.last_dir, pico.last_step_us, pico.enabled)
            _last_sent_asc = cmd_asc
            log_h.info("ASC commanded=%s: %s", cmd_asc, reply)
        if needs_write(_last_sent_dec, cmd_dec):
            reply = await _serial_call(pico.set_speed_dec, cmd_dec)
            tracker.dec.set_command(
                pico.last_dec_dir, pico.last_dec_step_us, pico.dec_enabled
            )
            _last_sent_dec = cmd_dec
            log_h.info("DEC commanded=%s: %s", cmd_dec, reply)
    except Exception as e:
        link_error = str(e)
        log_h.warning("speed apply serial error: %s", e)
        await _close_pico()
        _request_rescan()
        await emit_motor_info(state, link="error")
        return False
    await emit_motor_info(state, link="connected")
    return True


async def handle_ctlparams(msg_type: str, msg: dict, state: Jobstate) -> None:
    global pico, ui_armed, link_error, _last_sent_asc, _last_sent_dec
    log_h = logging.getLogger("handle_ctlparams")

    if msg_type != "ctlparams":
        return

    key = msg.get("k")
    val = msg.get("v")
    log_h.info("ctlparams %s=%s", key, val)

    if key == CTL_MOTOR_ARM:
        ui_armed = True
        if pico is not None:
            try:
                await _serial_call(pico.ping)
                link_error = None
                log_h.info("MOTOR_ARM — Pico healthy on %s", pico.port)
                await emit_motor_info(state, link="connected")
                return
            except Exception as e:
                link_error = str(e)
                log_h.warning("MOTOR_ARM — ping failed, rescanning: %s", e)
                await _close_pico()
                _request_rescan()
                await emit_motor_info(state, link="error")
                return
        log_h.info("MOTOR_ARM — no Pico yet, requesting scan")
        _request_rescan()
        await emit_motor_info(state, link="searching")
        return

    if key == CTL_MOTOR_DISARM:
        ui_armed = False
        mixer.disable()
        log_h.info("MOTOR_DISARM")
        if pico is not None:
            await _apply_mixed_speeds(state, log_h)
        else:
            await emit_motor_info(state)
        return

    if key == CTL_ASC:
        mixer.set_ff_asc(float(val))
        await _apply_mixed_speeds(state, log_h)
        return

    if key == CTL_DEC:
        mixer.set_ff_dec(float(val))
        await _apply_mixed_speeds(state, log_h)
        return

    if key == CTL_ASC_SIDEREAL:
        mixer.set_ff_asc(sidereal_speed_cmd())
        await _apply_mixed_speeds(state, log_h)
        return

    if key == CTL_GUIDE_ENABLE:
        if not ui_armed or pico is None:
            log_h.warning(
                "GUIDE_ENABLE refused — armed=%s pico=%s",
                ui_armed,
                pico is not None,
            )
            await emit_motor_info(state)
            return
        mixer.enable()
        log_h.info("GUIDE_ENABLE")
        await _apply_mixed_speeds(state, log_h)
        return

    if key == CTL_GUIDE_DISABLE:
        mixer.disable()
        log_h.info("GUIDE_DISABLE")
        if pico is not None:
            await _apply_mixed_speeds(state, log_h)
        else:
            await emit_motor_info(state)
        return

    if key == CTL_GUIDE_DASC:
        now = time.monotonic()
        if not mixer.set_trim_asc(float(val), now):
            log_h.info("GUIDE_DASC ignored — guide not enabled")
            return
        await _apply_mixed_speeds(state, log_h)
        return

    if key == CTL_GUIDE_DDEC:
        now = time.monotonic()
        if not mixer.set_trim_dec(float(val), now):
            log_h.info("GUIDE_DDEC ignored — guide not enabled")
            return
        await _apply_mixed_speeds(state, log_h)
        return

    if key == CTL_ASC_ZERO:
        tracker.asc.zero()
        log_h.info("ASC_ZERO")
        return

    if key == CTL_DEC_ZERO:
        tracker.dec.zero()
        log_h.info("DEC_ZERO")
        return

    if key == CTL_ASC_RESET:
        mixer.set_ff_asc(0.0)
        mixer.clear_asc_trim()
        if pico is not None:
            try:
                reply = await _serial_call(pico.hard_stop_asc)
                tracker.asc.stop()
                _last_sent_asc = 0.0
                log_h.info("ASC_RESET → hard stop: %s", reply)
                await emit_motor_info(state, link="connected")
            except Exception as e:
                link_error = str(e)
                log_h.warning("ASC_RESET serial error: %s", e)
                await _close_pico()
                _request_rescan()
                await emit_motor_info(state, link="error")
        return

    if key == CTL_DEC_RESET:
        mixer.set_ff_dec(0.0)
        mixer.clear_dec_trim()
        if pico is not None:
            try:
                reply = await _serial_call(pico.hard_stop_dec)
                tracker.dec.stop()
                _last_sent_dec = 0.0
                log_h.info("DEC_RESET → hard stop: %s", reply)
                await emit_motor_info(state, link="connected")
            except Exception as e:
                link_error = str(e)
                log_h.warning("DEC_RESET serial error: %s", e)
                await _close_pico()
                _request_rescan()
                await emit_motor_info(state, link="error")
        return

    if key in (CTL_DEC_CURR, CTL_ASC_CURR):
        log_h.info("ignored (no TMC UART current yet): %s=%s", key, val)
        return

    log_h.info("unknown ctlparams key: %s", key)


@infiniteRetry(rerunTiming=2)
async def motor_ws_job(uri: str, state: Jobstate) -> None:
    await clientConnection(uri, handle_ctlparams, state)


async def _wait_rescan_or_timeout(timeout_s: float) -> None:
    """Sleep until force_rescan or timeout; clear the event if set."""
    if force_rescan is None:
        await asyncio.sleep(timeout_s)
        return
    try:
        await asyncio.wait_for(force_rescan.wait(), timeout=timeout_s)
    except asyncio.TimeoutError:
        return
    finally:
        force_rescan.clear()


async def motor_serial_job(port: Optional[str], state: Jobstate) -> None:
    """Scan / open / telemetry loop — never exits; no systemd restart needed."""
    global pico, link_error

    while True:
        try:
            # --- searching / open ---
            while pico is None:
                try:
                    resolved = resolve_pico_port_required(port)
                except PicoNotFoundError as e:
                    link_error = str(e)
                    await emit_motor_info(state, link="searching")
                    await _wait_rescan_or_timeout(SEARCH_PERIOD_S)
                    continue

                log.info("opening Pico ASC/DEC on %s", resolved)
                try:
                    if serial_lock is None:
                        client = await asyncio.to_thread(_open_pico_client, resolved)
                    else:
                        async with serial_lock:
                            client = await asyncio.to_thread(
                                _open_pico_client, resolved
                            )
                except Exception as e:
                    link_error = str(e)
                    log.warning("open failed on %s: %s", resolved, e)
                    await emit_motor_info(state, link="error")
                    await _wait_rescan_or_timeout(SEARCH_PERIOD_S)
                    continue

                pico = client
                link_error = None
                tracker.stop_all()
                log.info("Pico linked on %s", resolved)
                await emit_motor_info(state, link="connected")

            # --- connected telemetry + health ---
            last_ping = time.monotonic()
            while pico is not None:
                if force_rescan is not None and force_rescan.is_set():
                    force_rescan.clear()
                    log.info("rescan requested — closing Pico link")
                    await _close_pico()
                    break

                now = time.monotonic()
                if now - last_ping >= PING_PERIOD_S:
                    try:
                        await _serial_call(pico.ping)
                        last_ping = now
                        link_error = None
                    except Exception as e:
                        link_error = str(e)
                        log.warning("health ping failed: %s", e)
                        await _close_pico()
                        await emit_motor_info(state, link="error")
                        break

                if mixer.expire(now):
                    await _apply_mixed_speeds(state, log)
                else:
                    await emit_motor_info(state, link="connected")
                await asyncio.sleep(TELEMETRY_PERIOD_S)
        except Exception:
            log.exception("motor_serial_job iteration failed; continuing")
            await asyncio.sleep(SEARCH_PERIOD_S)


async def main(uri: str, port: Optional[str]) -> None:
    global force_rescan, serial_lock
    force_rescan = asyncio.Event()
    serial_lock = asyncio.Lock()
    state = Jobstate()
    task_ws = asyncio.create_task(motor_ws_job(uri, state))
    task_serial = asyncio.create_task(motor_serial_job(port, state))
    await task_ws
    await task_serial


def parse_motor_args(argv=None):
    parser = argparse.ArgumentParser(description="ASC+DEC Pico motor worker")
    parser.add_argument(
        "--uri",
        default="ws://localhost:8765/motor",
        help="rootserver motor WebSocket URI",
    )
    parser.add_argument(
        "--port",
        default=None,
        help="serial port (default: first Pico vid 2e8a; no ACM0/COM5 fallback)",
    )
    return parser.parse_args(argv)


if __name__ == "__main__":
    logging.basicConfig(level=logging.INFO, format=formatstr)
    args = parse_motor_args()
    asyncio.run(main(args.uri, args.port))

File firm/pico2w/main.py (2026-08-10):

"""Pico 2 W — ASC + DEC stepper controller over USB serial.

Receives sparse text commands from the Raspberry Pi; generates STEP pulses
locally. Rate setpoints ease over ~100 ms (signed rate) so period changes do
not inject ghost steps. No TMC UART yet (standalone STEP/DIR).
See README.md in this folder for the host protocol.
"""

from machine import Pin
import sys
import time
import uselect

# Motor 1 = ASC (ascension)
PIN_ASC_DIR = 10
PIN_ASC_STEP = 11
PIN_ASC_EN = 12

# Motor 2 = DEC
PIN_DEC_DIR = 18
PIN_DEC_STEP = 19
PIN_DEC_EN = 20

# STEP pulse high time (us). Period between steps comes from current rate.
PULSE_HIGH_US = 4
MIN_STEP_US = 50
MAX_STEP_US = 10_000_000
RAMP_MS = 100
RATE_EPS = 0.5  # below this |rate|, treat as stopped

led = Pin("LED", Pin.OUT)

poll = uselect.poll()
poll.register(sys.stdin, uselect.POLLIN)
_rx = ""


def _clamp_step_us(period_us):
    period_us = int(period_us)
    if period_us <= 0:
        return 0
    if period_us < MIN_STEP_US:
        return MIN_STEP_US
    if period_us > MAX_STEP_US:
        return MAX_STEP_US
    return period_us


def _period_to_rate(dir_bit, step_us):
    """Signed steps/s from commanded dir + period. 0 period → 0 rate."""
    step_us = _clamp_step_us(step_us)
    if step_us <= 0:
        return 0.0
    rate = 1_000_000.0 / float(step_us)
    return rate if int(dir_bit) == 0 else -rate


class Motor:
    def __init__(self, name, pin_dir, pin_step, pin_en):
        self.name = name
        self.dir_pin = Pin(pin_dir, Pin.OUT, value=0)
        self.step_pin = Pin(pin_step, Pin.OUT, value=0)
        self.en_pin = Pin(pin_en, Pin.OUT, value=1)  # ENN high = disabled
        self.enabled = False
        self.cmd_dir = 0
        self.cmd_step_us = 0
        self.target_rate = 0.0
        self.current_rate = 0.0
        self._ramp_from = 0.0
        self._ramp_to = 0.0
        self._ramp_t0_ms = time.ticks_ms()
        self._ramping = False
        self._next_step_us = time.ticks_us()

    def set_enabled(self, on):
        self.enabled = bool(on)
        self.en_pin.value(0 if self.enabled else 1)

    def hard_stop(self):
        """Immediate disable — used by stop / en=0."""
        self.target_rate = 0.0
        self.current_rate = 0.0
        self.cmd_step_us = 0
        self._ramping = False
        self.set_enabled(False)
        self.step_pin.value(0)

    def _start_ramp(self, new_target):
        self._ramp_from = self.current_rate
        self._ramp_to = float(new_target)
        self.target_rate = self._ramp_to
        self._ramp_t0_ms = time.ticks_ms()
        self._ramping = True
        if abs(self._ramp_to) > RATE_EPS and not self.enabled:
            self.set_enabled(True)
            # First motion: schedule first pulse after one period at start rate
            # (or target if starting from zero — use a gentle initial period).
            start_abs = abs(self._ramp_from)
            if start_abs < RATE_EPS:
                start_abs = abs(self._ramp_to)
            period = _clamp_step_us(int(round(1_000_000.0 / start_abs)))
            self._next_step_us = time.ticks_add(time.ticks_us(), period)

    def apply_command(self, args):
        """Apply asc/dec key=value args. Mutates motor state."""
        if "dir" in args:
            self.cmd_dir = 1 if int(args["dir"]) else 0

        force_en = None
        if "en" in args or "enable" in args:
            force_en = args.get("en", args.get("enable"))
            if int(force_en) == 0:
                self.hard_stop()
                return
            self.set_enabled(True)

        period = None
        if "step_us" in args:
            period = _clamp_step_us(args["step_us"])
        elif "step_time" in args:
            period = _clamp_step_us(args["step_time"])

        if period is not None:
            self.cmd_step_us = period
            if period <= 0:
                self._start_ramp(0.0)
            else:
                if force_en is None and not self.enabled:
                    self.set_enabled(True)
                self._start_ramp(_period_to_rate(self.cmd_dir, period))
        elif "dir" in args and self.cmd_step_us > 0 and self.enabled:
            # Direction-only change while moving: retarget signed rate.
            self._start_ramp(_period_to_rate(self.cmd_dir, self.cmd_step_us))

    def update_ramp(self):
        if not self._ramping:
            return
        elapsed = time.ticks_diff(time.ticks_ms(), self._ramp_t0_ms)
        if elapsed >= RAMP_MS:
            self.current_rate = self._ramp_to
            self._ramping = False
            if abs(self.current_rate) < RATE_EPS:
                self.current_rate = 0.0
                self.cmd_step_us = 0
                self.set_enabled(False)
            return
        if elapsed <= 0:
            self.current_rate = self._ramp_from
            return
        t = elapsed / float(RAMP_MS)
        self.current_rate = self._ramp_from + (self._ramp_to - self._ramp_from) * t

    def maybe_step(self):
        self.update_ramp()
        if not self.enabled or abs(self.current_rate) < RATE_EPS:
            return
        period = _clamp_step_us(int(round(1_000_000.0 / abs(self.current_rate))))
        if period <= 0:
            return
        dir_bit = 0 if self.current_rate > 0 else 1
        self.dir_pin.value(dir_bit)

        now = time.ticks_us()
        if time.ticks_diff(now, self._next_step_us) < 0:
            return
        self.step_pin.value(1)
        time.sleep_us(PULSE_HIGH_US)
        self.step_pin.value(0)
        # Advance from previous deadline; do not reset to now (avoids ghost steps).
        self._next_step_us = time.ticks_add(self._next_step_us, period)
        # If badly behind, resync without bursting catch-up pulses.
        if time.ticks_diff(now, self._next_step_us) > period:
            self._next_step_us = now
        led.toggle()

    def status_tokens(self):
        """Tokens for status / command reply (commanded target)."""
        return "motor=%s en=%d dir=%d step_us=%d" % (
            self.name,
            1 if self.enabled else 0,
            self.cmd_dir,
            self.cmd_step_us,
        )


asc = Motor("asc", PIN_ASC_DIR, PIN_ASC_STEP, PIN_ASC_EN)
dec = Motor("dec", PIN_DEC_DIR, PIN_DEC_STEP, PIN_DEC_EN)
MOTORS = {"asc": asc, "dec": dec, "motor": asc}


def reply(msg):
    sys.stdout.write(msg + "\n")
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

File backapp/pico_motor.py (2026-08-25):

"""Pico 2 W ASC + DEC stepper host client (USB serial text protocol).

Protocol: firm/pico2w/README.md
"""

from __future__ import annotations

import time
from typing import Optional, Tuple

import serial
import serial.tools.list_ports

BAUD = 115200
MIN_STEP_US = 50
MAX_STEP_US = 10_000_000
DEFAULT_PORT_WIN = "COM5"
DEFAULT_PORT_LINUX = "/dev/ttyACM0"

# Flip if mount direction is inverted relative to UI positive speed.
DIR_INVERT_ASC = False
DIR_INVERT_DEC = False


class PicoNotFoundError(LookupError):
    """No Raspberry Pi Pico USB CDC device is present."""


def find_pico_ports() -> list[str]:
    """Prefer Raspberry Pi Pico USB CDC (vid 2e8a)."""
    ports = []
    for p in serial.tools.list_ports.comports():
        if p.vid == 0x2E8A:
            ports.append(p.device)
    return ports


def resolve_pico_port_required(preferred: Optional[str] = None) -> str:
    """Return preferred port or first Pico VID match; raise if none."""
    if preferred:
        return preferred
    found = find_pico_ports()
    if found:
        return found[0]
    raise PicoNotFoundError("no Pico USB CDC (vid 2e8a) found")


def resolve_pico_port(preferred: Optional[str] = None) -> str:
    """Return preferred port, else first Pico VID match, else platform default.

    Prefer :func:`resolve_pico_port_required` for the motor worker so a missing
    board does not open a stale ``/dev/ttyACM0`` / ``COM5``.
    """
    try:
        return resolve_pico_port_required(preferred)
    except PicoNotFoundError:
        import sys

        return DEFAULT_PORT_WIN if sys.platform.startswith("win") else DEFAULT_PORT_LINUX


def speed_to_dir_step_us(
    speed: float, *, invert: bool = False
) -> Tuple[int, Optional[int]]:
    """Map signed steps/sec to (dir, step_us).

    speed == 0 → (dir unchanged conceptually, None) meaning stop.
    Positive speed → dir=0 (unless invert).
    """
    speed = float(speed)
    if speed == 0:
        return (0, None)

    dir_bit = 0 if speed > 0 else 1
    if invert:
        dir_bit ^= 1

    step_us = int(round(1_000_000.0 / abs(speed)))
    if step_us < MIN_STEP_US:
        step_us = MIN_STEP_US
    if step_us > MAX_STEP_US:
        step_us = MAX_STEP_US
    return dir_bit, step_us


def parse_status_fields(reply: str) -> dict:
    """Parse a single-axis reply ``ok motor=asc en=1 dir=0 step_us=2000``.

    For dual-axis ``status`` lines, use :func:`parse_dual_status`.
    """
    out = {}
    for token in reply.split():
        if "=" not in token:
            continue
        key, val = token.split("=", 1)
        key = key.lower()
        if key in ("en", "dir", "step_us"):
            try:
                out[key] = int(val)
            except ValueError:
                out[key] = val
        else:
            out[key] = val
    return out


def parse_dual_status(reply: str) -> dict[str, dict]:
    """Parse ``ok asc en=1 dir=0 step_us=2000 dec en=0 dir=0 step_us=0``.

    Also accepts single-motor ``ok motor=asc en=…`` → ``{"asc": {...}}``.
    """
    tokens = reply.split()
    # Single-motor command reply
    if any(t.lower().startswith("motor=") for t in tokens):
        fields = parse_status_fields(reply)
        name = str(fields.get("motor", "asc")).lower()
        axis = {
            k: fields[k] for k in ("en", "dir", "step_us") if k in fields
        }
        return {name: axis}

    axes: dict[str, dict] = {}
    current: Optional[str] = None
    for token in tokens:
        low = token.lower()
        if low in ("asc", "dec"):
            current = low
            axes.setdefault(current, {})
            continue
        if current is None or "=" not in token:
            continue
        key, val = token.split("=", 1)
        key = key.lower()
        if key in ("en", "dir", "step_us"):
            try:
                axes[current][key] = int(val)
            except ValueError:
                axes[current][key] = val
    return axes


class PicoMotorClient:
    def __init__(self, port: str, baud: int = BAUD, timeout: float = 1.0):
        self.port = port
        # Opening USB CDC often resets MicroPython; wait for boot before I/O.
        self.ser = serial.Serial(port, baud, timeout=timeout)
        time.sleep(2.0)
        self.ser.reset_input_buffer()
        self.ser.reset_output_buffer()
        self.last_dir = 0
        self.last_step_us = 0
        self.enabled = False
        self.last_dec_dir = 0
        self.last_dec_step_us = 0
        self.dec_enabled = False

    def close(self) -> None:
        try:
            self.cmd("stop")
        except Exception:
            pass
        try:
            self.ser.close()
        except Exception:
            pass
        self.enabled = False
        self.last_step_us = 0
        self.dec_enabled = False
        self.last_dec_step_us = 0

    def cmd(self, line: str) -> str:
        payload = (line.strip() + "\n").encode("ascii")
        self.ser.write(payload)
        self.ser.flush()
        raw = self.ser.readline()
        if not raw:
            raise TimeoutError(f"no reply for: {line!r}")
        text = raw.decode("ascii", errors="replace").strip()
        if text.startswith("err"):
            raise RuntimeError(f"pico error for {line!r}: {text}")
        if not text.startswith("ok"):
            raise RuntimeError(f"unexpected reply for {line!r}: {text}")
        return text

    def drain_boot(self) -> list[str]:
        """Read any pending boot lines without failing if none."""
        lines = []
        old = self.ser.timeout
        self.ser.timeout = 0.2
        try:
            while True:
                line = self.ser.readline()
                if not line:
                    break
                lines.append(line.decode("ascii", errors="replace").strip())
        finally:
            self.ser.timeout = old
        return lines

    def ping(self) -> str:
        return self.cmd("ping")

    def _apply_axis_fields(self, name: str, fields: dict) -> None:
        if name == "asc":
            if "dir" in fields:
                self.last_dir = int(fields["dir"])
            if "step_us" in fields:
                self.last_step_us = int(fields["step_us"])
            if "en" in fields:
                self.enabled = bool(fields["en"])
        elif name == "dec":
            if "dir" in fields:
                self.last_dec_dir = int(fields["dir"])
            if "step_us" in fields:
                self.last_dec_step_us = int(fields["step_us"])
            if "en" in fields:
                self.dec_enabled = bool(fields["en"])

    def status(self) -> str:
        reply = self.cmd("status")
        for name, fields in parse_dual_status(reply).items():
            self._apply_axis_fields(name, fields)
        return reply

    def stop(self) -> str:
        reply = self.cmd("stop")
        self.last_step_us = 0
        self.enabled = False
        self.last_dec_step_us = 0
        self.dec_enabled = False
        return reply
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

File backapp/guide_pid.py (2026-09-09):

"""PI rate trims on axis-pixel error. Kd stays 0 (evolution §5).

Error is e_asc_px / e_dec_px (not e_*_steps). At 18 mm, a few pixels of
lock error must not rail the mixer.
"""

from __future__ import annotations

from dataclasses import dataclass

from guide_mixer import TRIM_ASC_MAX, TRIM_DEC_MAX, clamp

# STEP/s per axis pixel. Sky traces at 0.25 / 0.02 hunted (ζ≈0.15, I-dominated).
# Plant G≈0.028 px/s per STEP/s at 18 mm bin2 → this pair is ζ≈0.75, Tn≈7 min.
# ~6 px → ~4.8 STEP/s P, still under the ±8 mixer rail.
KP = 0.80
KI = 0.008
KP_MIN, KP_MAX = 0.0, 4.0
KI_MIN, KI_MAX = 0.0, 0.5
KD = 0.0
DT_MIN = 0.05
DT_MAX = 1.0
LOST_HOLD_N = 8
LOST_DROP_S = 5.0
DEADBAND_PX = 0.5


def clamp_dt(dt: float) -> float:
    return clamp(float(dt), DT_MIN, DT_MAX)


def clamp_kp(v) -> float:
    try:
        x = float(v)
    except (TypeError, ValueError):
        x = KP
    if x != x:  # NaN
        x = KP
    return clamp(x, KP_MIN, KP_MAX)


def clamp_ki(v) -> float:
    try:
        x = float(v)
    except (TypeError, ValueError):
        x = KI
    if x != x:
        x = KI
    return clamp(x, KI_MIN, KI_MAX)


@dataclass
class AxisPI:
    kp: float = KP
    ki: float = KI
    out_max: float = TRIM_ASC_MAX
    i: float = 0.0
    last_out: float = 0.0
    freeze_i: bool = False

    def reset(self) -> None:
        self.i = 0.0
        self.last_out = 0.0
        self.freeze_i = False

    def update(
        self,
        e_px: float,
        dt: float,
        *,
        in_deadband: bool = False,
        force_zero: bool = False,
    ) -> float:
        if force_zero:
            self.freeze_i = True
            self.last_out = 0.0
            return 0.0
        e = float(e_px)
        if in_deadband:
            return self.last_out
        p = self.kp * e
        raw = p + self.i
        sat = clamp(raw, -self.out_max, self.out_max)
        unsaturated = abs(raw) <= self.out_max + 1e-15
        would_unwind = (self.i * e) < 0.0
        if not self.freeze_i and (unsaturated or would_unwind):
            self.i = clamp(
                self.i + self.ki * e * float(dt),
                -self.out_max,
                self.out_max,
            )
            sat = clamp(p + self.i, -self.out_max, self.out_max)
        self.last_out = sat
        return sat
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

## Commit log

2020-03-08 adding first version of arduino code
2020-03-08 bridging arduino to mqtt
2020-11-20 adding motor control script
2021-03-21 updating motorControl Code
2021-03-22 camera update
2021-03-22 updating motorControl for py
2021-03-22 adding motor stats
2021-04-03 adding a new method for camera
2021-04-04 updating camera
2021-05-02 updating motor code
2021-05-06 updating framerate range setting
2021-05-06 updating camera exposition time
2021-05-22 adding stepper control
2021-05-28 adding control for stepper
2021-06-12 adding stepper test
2021-07-01 up stepper control
2021-11-15 adding gyro code
2026-08-09 Add camera bench scripts and Pico 2 W firmware docs.
    EOF
2026-08-09 Replace Sony camera path with picamera2 stack, tests, deploy, and docs.
    [cam_picamera2.py, cam_settings.py, cam_spectrum.py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]
2026-08-10 Rework the wasp UI for night ops: compact connect with last host, scrollable camera panel, and clearer capture/save flow.
2026-08-10 Fix camera UI params: push controls and hydrate once on connect.
    Controls only sent save toggles before, and Vue _-prefixed hydrate flags never stuck so live imgProps rewrote selects every frame. Push on user input, snapshot settings once per connect, and seed hub currentParams from the camera for reconnect.
    [rootserver.py, test_rootserver_hub.py]
2026-08-10 Replace absolute preview size with aspect-preserving preview_div.
    UI sends full/1/2/1/4/1/8; camera downsamples JPEG from capture RGB without distorting ratio; browser scales the image to fill the stage. Also make HUD controls transparent.
    [cam_picamera2.py, cam_settings.py, test_cam_settings_bench.py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]
2026-08-25 Harden Pico motor link with arm/disarm, live status, and USB CDC discovery.
    Drop obsolete notebooks and add locs.yml for observer windows.
2026-08-29 adding pieces
    [barlow_adaptor.3mf, barlow_adaptor.scad, barlow_adaptor.stl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]
2026-08-30 Add the motor-board enclosure and M42 adaptor, and refresh the other printed models.
    Keep the OpenSCAD sources together with their README notes and exported STL/3MF so the printed parts stay in sync.
    [barlow_adaptor.3mf, barrel_adapter.scad, m42_to_1_25.scad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]
2026-08-30 Recover Unicam hangs so the camera worker cannot sit at 0 fps after a bad start.
    Timeout the first and later captures, reopen on soft failures, and exit so systemd Restart=always can recover a poisoned capture thread.
    [cam_picamera2.py, cam_stream_recovery.py, test_cam_stream_recovery.py]
2026-08-30 updating motor box
    [barrel_adapter.scad, cover.stl, motor_board_box.scad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]
2026-09-04 Add evolution plan for a camera-to-motor autoguide loop.
    Documents a sidereal feedforward plus two-axis PI trim on one lock
    star, with ASC error normalized by cos(dec) so PID gains stay stable
    from equator to high declination.
2026-09-04 Clarify why the autoguide loop is PI-only, and what to try before D.
    Record that I eats sidereal/polar bias, D on raw centroids chases seeing,
    and a drift-rate estimator (then PEC) is the upgrade path—not Kd or MPC.
2026-09-04 Split the HQ camera holder into a frozen cover and three nosepiece bodies.
    Keep printed-cover geometry unchanged while adding 1.25, short 2 inch, and CS-open plates as separate files.
    [body_1_25.scad, body_2.scad, body_open.scad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]
2026-09-04 Add preview locator overlay and Pi package/deploy scripts.
    Locator is burned into the preview JPEG only. Deploy scripts sync backapp to the Pi and serve the compiled wasp UI on port 80.
    [cam_locator.py, cam_picamera2.py, cam_settings.py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]
2026-09-06 Add closed-loop autoguide on the Pi and wasp: isolate, PI trims, mixer, and tracking traces.
    Skip savedimgs (large local Bayer dumps). Leave 3dmodels untracked.
    [cam_locator.py, cam_picamera2.py, cam_settings.py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]
2026-09-06 Add the scope T-plate and the motor-board box cover.
    [cover.3mf, scope_t_plate.scad, scope_t_plate.stl]
2026-09-09 Retune default autoguide PI gains from on-sky hunting traces.
    Kp 0.25 / Ki 0.02 was I-dominated (zeta ~0.15) and limit-cycled; 0.80 / 0.008 raises damping and slows integral windup. Add scripts to plot traces and separate loop hunt from drivetrain PE.
